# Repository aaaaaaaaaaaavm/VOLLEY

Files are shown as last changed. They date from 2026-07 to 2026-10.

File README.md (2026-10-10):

# VOLLEY

### A computational design study for sequential CubeSat deployment

VOLLEY studies a host-mounted electromagnetic machine that would feed ordinary 3U CubeSats through one reusable launch path and command an individual departure speed for each release. **Gen5 is the controlled academic evaluation snapshot, with a negative 3U selection finding.** Its final engineering release and academic freeze are open. Gen6 is the proposed first instrumented prototype programme, with its speed and accuracy to be derived from a named mission and payload. A 1 km/s-class release is a separate long-range research objective; Gen6 has no selected mechanism or validated performance.

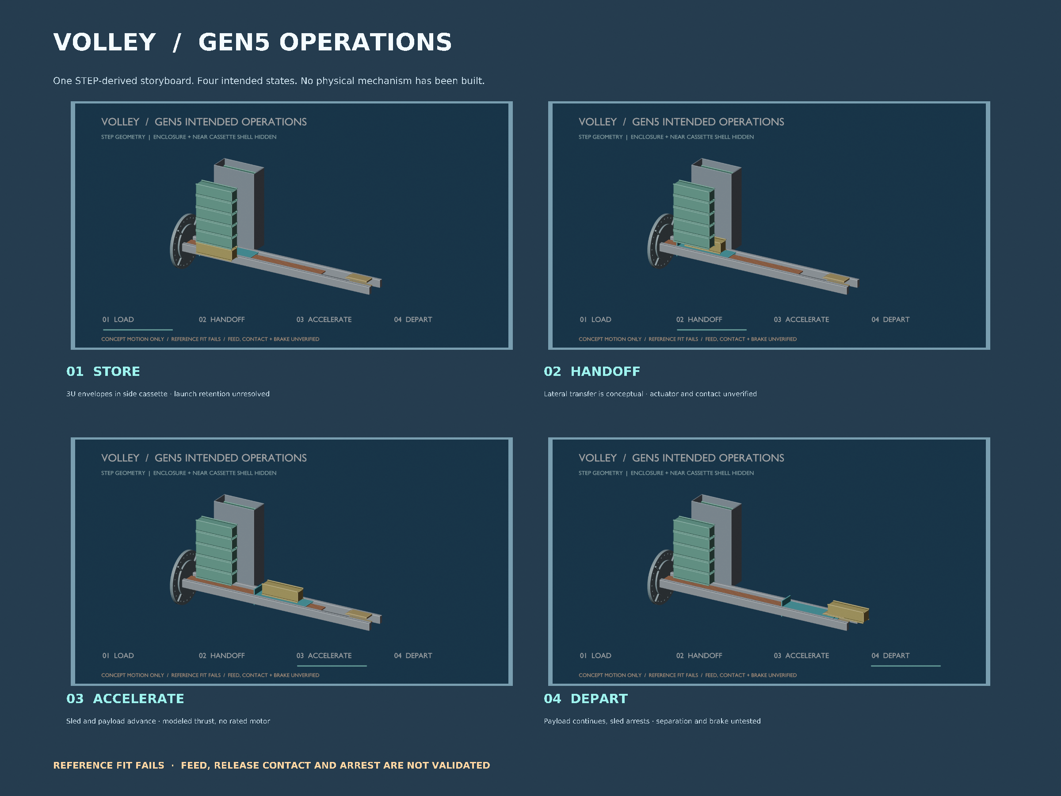
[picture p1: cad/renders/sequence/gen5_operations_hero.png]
Four-stage STEP-derived Blender storyboard of intended Gen5 storage, handoff, acceleration and departure


*Intended operations, not validated motion. The enclosure and near cassette shell are hidden for visibility. The evaluated side-fed assembly **fails** its static fit check; feed, contact and brake dynamics remain unverified. [Watch the eight-second conceptual animation](cad/renders/sequence/gen5_intended_sequence.mp4) · [inspect its STEP sources and provenance](cad/renders/sequence/README.md) · [open the interactive website](https://aaaaaaaaaaaavm.github.io/VOLLEY/).*

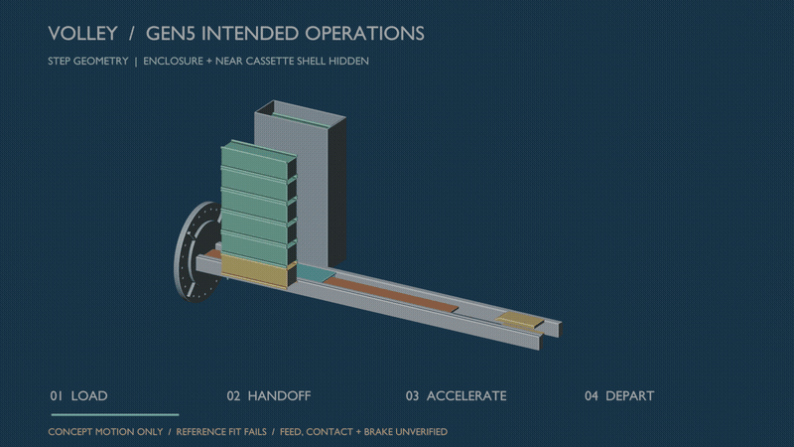
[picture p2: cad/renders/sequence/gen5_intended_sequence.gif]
Concept animation of intended Gen5 storage, lateral handoff, track motion and departure; motion is not validated


**Read first:** [Computational review report](reports/GEN5_COMPUTATIONAL_REVIEW.pdf) · [FreeCAD/CAD report](cad/GEN5_CAD_REVIEW.pdf) · [Gen5 freeze readiness](docs/GEN5_FREEZE_READINESS.md) · [Remaining CAD and IEEE work](IEEE_AND_CAD_REMAINING_WORK.md) · [IEEE prior-art update](docs/IEEE_PRIOR_ART_UPDATE_2026-10-09.md) · [Market and spacecraft fit](MARKET_AND_CUSTOMER_FIT.md) · [Gen5 technical closure](docs/GEN5_CLOSURE.md) · [Full baseline](docs/BASELINE.md) · [Evidence provenance](docs/PROVENANCE.md) · [Open problems](OPEN_PROBLEMS.md) · [CAD](cad/README.md) · [Validation](validation/README.md)

> **Evidence status, October 2026.** Gen5 is the selected computational design for academic review. Its configuration, model results and failed criteria are documented; [decisive verification items remain open](docs/GEN5_FREEZE_READINESS.md), so the final academic freeze has not been declared. No VOLLEY article has been built, fired, measured, qualified or flown; no complete installed-system or provider-specific interface has been validated. Published work on related systems is prior art and a source of assumptions, not a physical test of Gen5.

> **Decisive new finding:** the CAD finite-array/stator force screen gives **12.448 m/s only under ideal phase and omitted circuit losses**, versus **16.029 m/s** in the historical periodic-force shot model. The historical value below is retained for traceability, not an established Gen5 performance claim. [Force map and numerical limits](validation/P118_gen5_finite_force_map.md) · [Affected claims and rerun decisions](docs/GEN5_2026_10_09_FINDING_DISPOSITION.md).

An [independent 2-D finite-element screen](validation/P119_gen5_finite_force_fem2d.md) now checks the finite-array force decline using a magnetostatic PDE instead of the cuboid field law. It gives **1,081.6 J ideal in-plane work** on a 1 mm mesh, compared with **1,041.7 J** in the 3-D analytic screen. Depth effects and coupled electrical behavior remain open, so neither result is a motor rating.

A [depth-resolved 3-D surface-charge cross-check](validation/P121_gen5_finite_force_surface3d.md) independently evaluates the finite cuboids and all 162 stator belts. It recovers **1,041.7 J** ideal work, with 16-to-24 point face quadrature changing work by **0.00002%** and 25-to-12.5 mm station spacing changing it by **0.096%**. The separate [gap and depth scenarios](validation/P122_gen5_finite_force_sensitivity.md) show **906.7 J at a 14 mm gap** versus 1,041.7 J at 12 mm. These are ideal-phase model checks with shared magnetic material assumptions, not motor ratings or hardware tolerances.

> **Installed-system decision, 10 October 2026:** the [P123 one-event mass screen](validation/P123_gen5_one_event_mass_screen.md) finds **1.866 kg** less host fuel used by ideal finite-force Gen5 than a spring class when both carry 10 kg, against **54.562 kg** greater modeled device dry mass. With fuel re-solved for that one event plus equal reserve, Gen5 remains **52.717 kg heavier** on device plus fuel. Ideal-speed parity would require about **52.630 kg** less Gen5 device mass; that is a quantified redesign screen, not a full mission or motor rating. [Recompute from source](analysis/gen5_one_event_mass_screen.py) · [captured result](analysis/results/gen5_one_event_mass_screen.json) · [six-gate evidence programme](docs/GEN5_EVIDENCE_BUILD_PROGRAMME.md).

> **Necessary bound for the next design:** even a perfect release needing no host preburn would require Gen5 device mass **≤74.659 kg** to tie this one-event spring reference; today's model is 126.562 kg. The [reproducible bound](analysis/gen5_architecture_bounds.py) shows that motor speed alone cannot close this specific gap. A [captive passive-armature and integrated-structure hypothesis](docs/GEN5_H1_INTEGRATED_DEPLOYER_HYPOTHESIS.md) is an unselected research direction, not a revised Gen5 result or a verified invention.

> **Precision delivery must be specified by the orbit, not by speed alone.** The [P124 design-space screen](validation/P124_precision_delivery_design_space.md) converts declared 450 km orbit targets into ideal tangential increments and velocity-error budgets. It also shows that 1 km/s over the Gen5 1.3 m stroke implies about **39,220 g** for an ordinary 4 kg 3U payload. The first Gen6 prototype needs a payload and mission-derived speed/load specification; the 1 km/s goal remains separate long-range research.

The [P127 release/arrest bounds](validation/P127_gen5_release_arrest_bounds.md) find 731.8 J of sled kinetic energy at the **ideal** finite-force speed. Over the provisional 210 mm brake corridor, stopping it needs at least 37.6 g mean sled deceleration; the first-order host reaction and net recoil are also bounded. Eddy-current peak force, payload contact, host attitude and repeated-shot thermal behavior remain unsolved.

The [P126 R1 tolerance screen](cad/FEEDER_R1_TOLERANCE_SCREEN.md) uses the R1 CAD-derived 5 mm lateral gap and declared alignment bands. A 0.2° band retains 1.31 mm; a 0.5° band overlaps by 0.47 mm. These are assumed tolerances, not measured fit or accepted mechanism clearances.

> **P125 drive feasibility screen:** A quasi-steady, three-phase voltage/current model uses the finite Gen5 force map and the historical **unselected** winding and 96 V source. The reference surrogate reaches 12.448 m/s; halving the current limit gives 8.802 m/s and halving the initial source voltage gives 10.794 m/s. A single string at the older 116–185 mΩ commercial ESR bound **fails the source-power equation before release**; ideal parallel-string branches complete while multiplying source cells and mass. These are conditional model outputs, **not a rated release speed or selected drive**. [Method and limits](validation/P125_gen5_voltage_limited_screen.md) · [source](analysis/gen5_voltage_limited_screen.py) · [result](analysis/results/gen5_voltage_limited_screen.json).

The [Gen6 prototype-to-flight roadmap](docs/GEN6_PROTOTYPE_TO_FLIGHT_ROADMAP.md) sets explicit mission, architecture, predictive-model, measured-prototype, engineering-model, qualification and flight decision gates. These are proposed development stages, not achieved milestones.

Ideal speed, stroke and payload-load screen

One-event installed device plus resized-fuel comparison

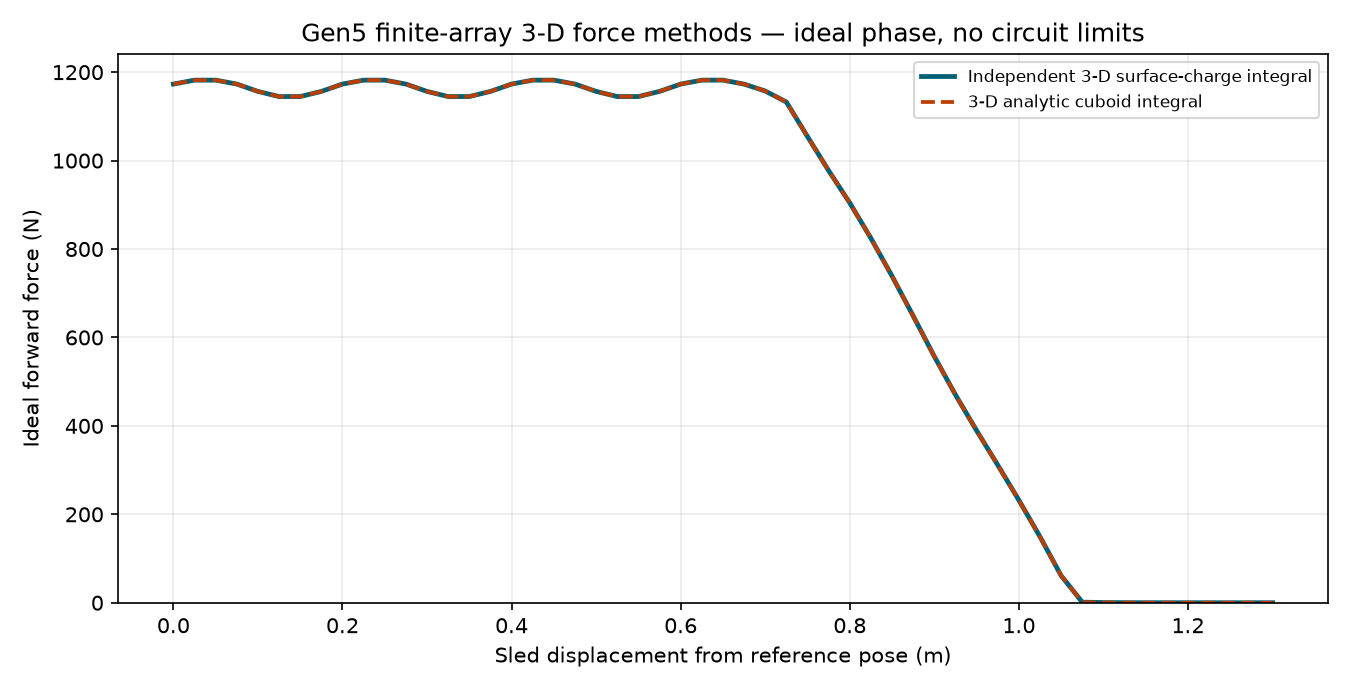
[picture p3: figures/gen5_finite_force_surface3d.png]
Independent numerical three-dimensional surface-charge force integration
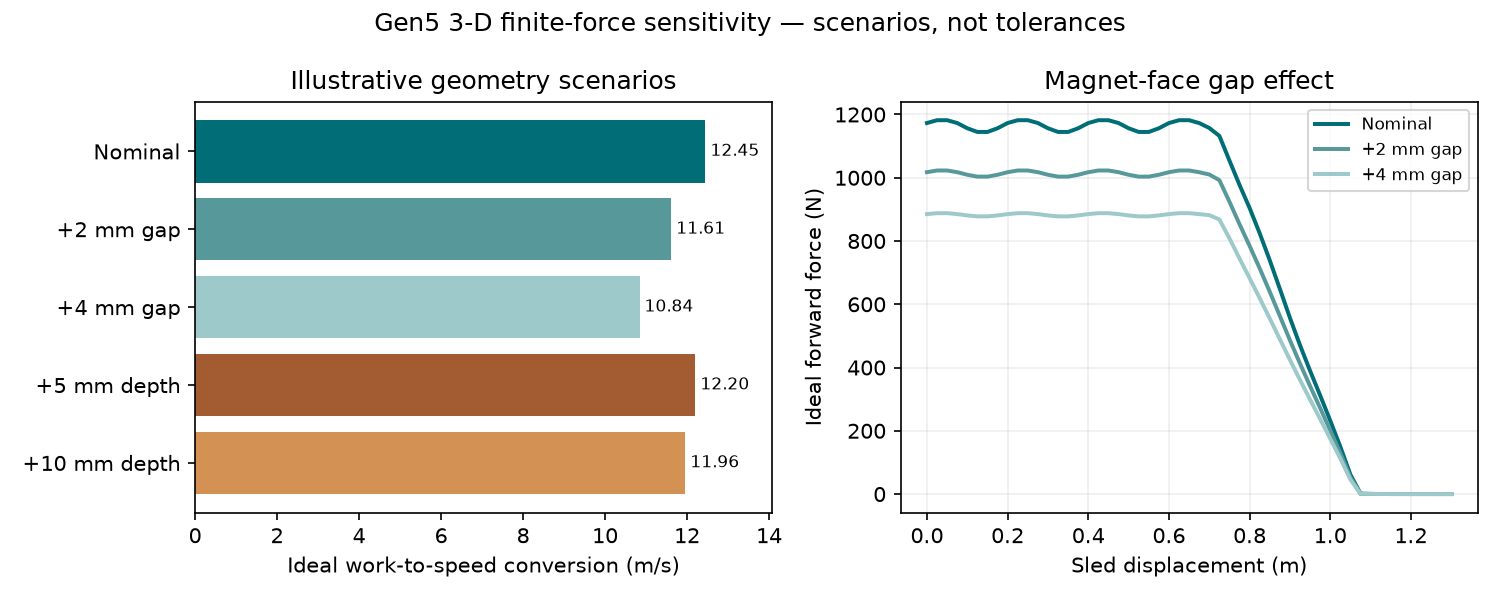
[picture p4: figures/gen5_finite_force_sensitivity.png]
Illustrative magnet gap and depth sensitivity scenarios


*Reproducible [P121 3-D numerical check](validation/P121_gen5_finite_force_surface3d.md) and [P122 deterministic scenarios](validation/P122_gen5_finite_force_sensitivity.md). The agreement checks the ideal finite-geometry integral; it does not select a winding, switching law or physical release speed.*

A [finite-force shot rerun](validation/P120_gen5_finite_coupled_shot.md) carries the P118 force profile through the historical capacitor/ESR model. With the old full-winding assumption it gives **12.448 m/s and 2.099 kJ gross draw**; a hypothetical segmented-copper branch gives the same ideal speed and **1.394 kJ**. These are conditional calculations using unselected power hardware and ideal phase at every position. The old energy, brake and precision figures cannot be transferred to them.

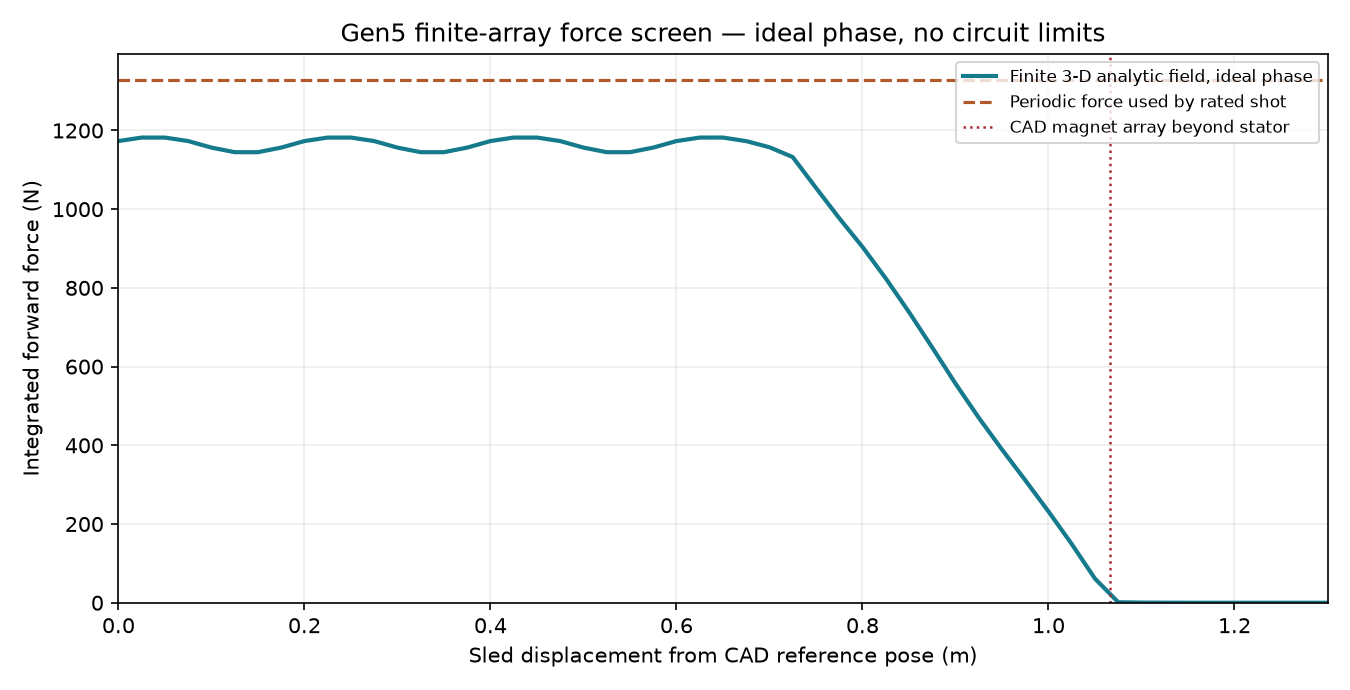
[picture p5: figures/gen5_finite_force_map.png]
Finite-stator force map and historical periodic assumption
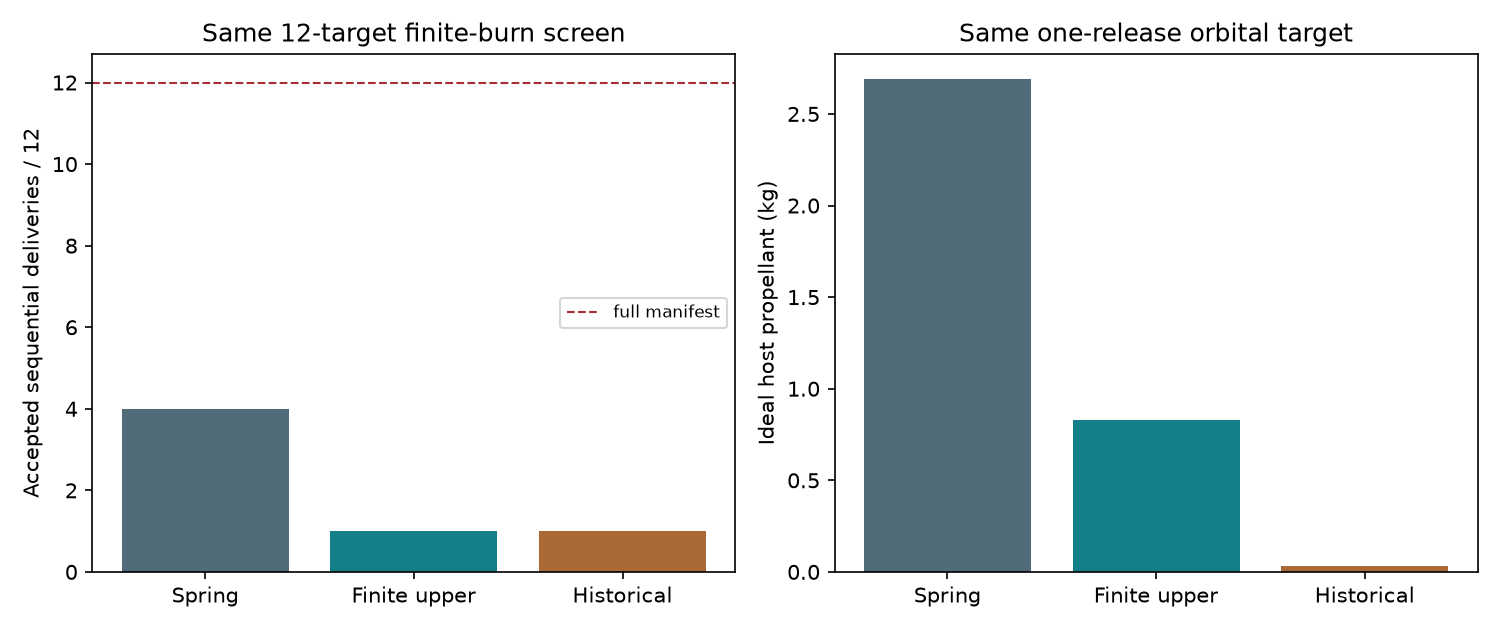
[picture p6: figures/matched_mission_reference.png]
Matched single-event and twelve-shot reference comparison


*New model screens: the finite-force result is analytic and shares the original magnetic field law; the matched mission uses assumed host and dispenser data. Neither is a physical result. [Mission assumptions and results](docs/MATCHED_MISSION_REFERENCE.md).*

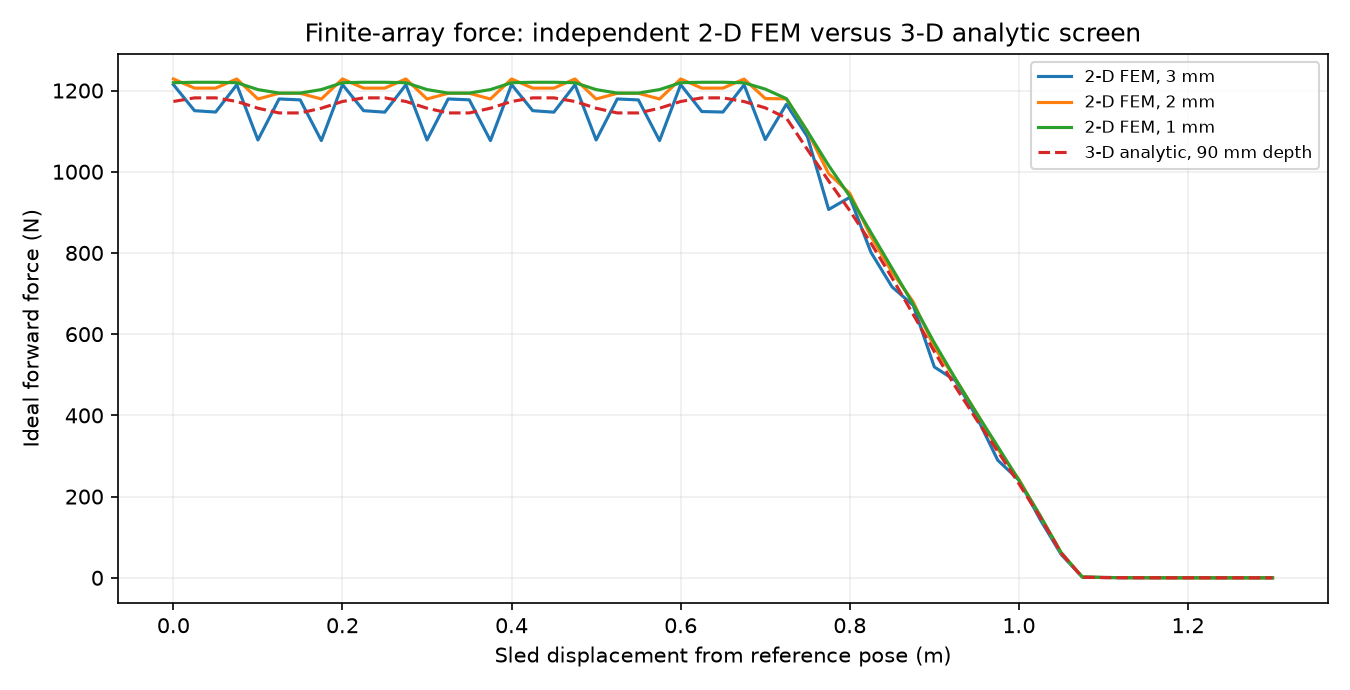
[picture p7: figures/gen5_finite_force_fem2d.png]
Independent two-dimensional finite-element force map compared with the three-dimensional analytic screen
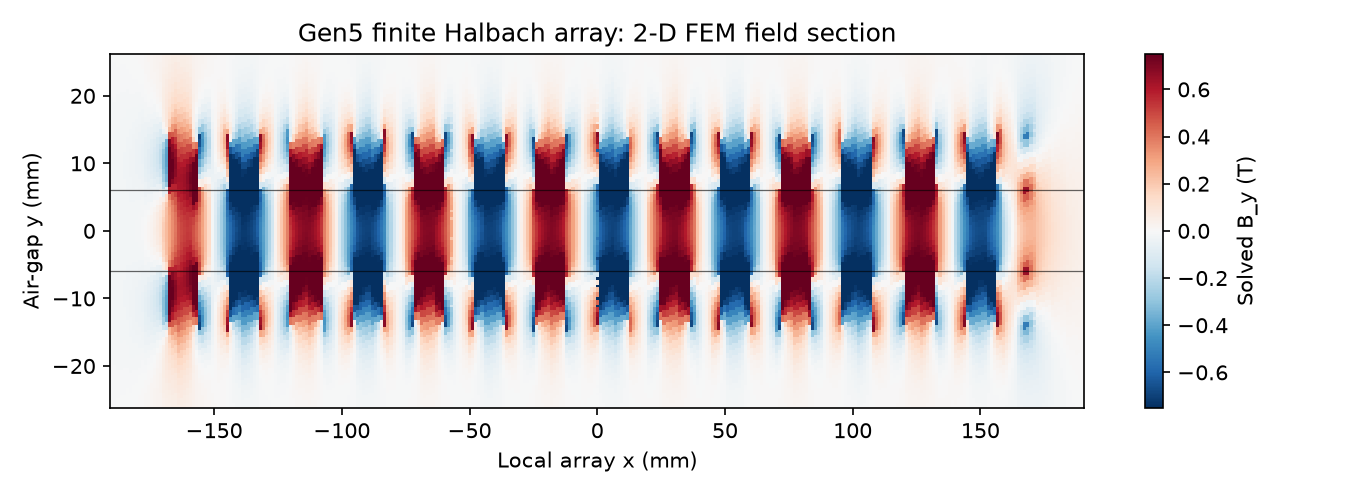
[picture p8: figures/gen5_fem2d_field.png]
Solved two-dimensional magnetic field around finite Halbach arrays


*Actual scikit-fem solver outputs, not CAD renders or physical measurements. The 2-D method omits finite magnet-depth effects; [P119](validation/P119_gen5_finite_force_fem2d.md) records mesh and boundary sensitivity.*

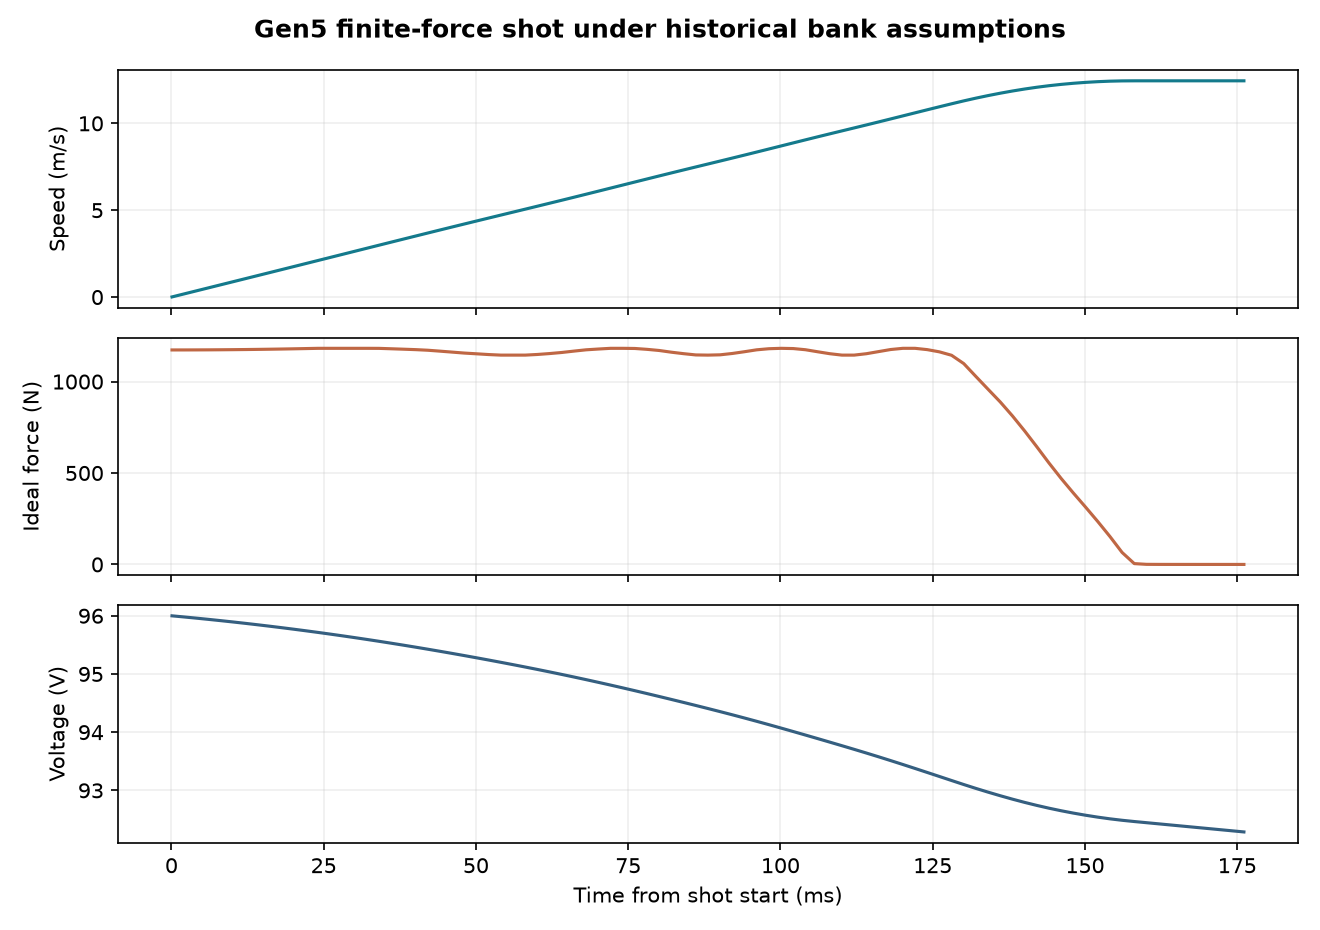
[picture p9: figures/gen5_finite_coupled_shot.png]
Finite-force shot under the historical bank assumptions


*Position-dependent model rerun, not a measured pulse or inverter validation. [P120 inputs, ledger and timestep check](validation/P120_gen5_finite_coupled_shot.md).*

## One machine, one evaluated configuration

Gen5 places the release station 1.5 m from the breech on 1.8 m structural longerons, with a 1.3 m powered stroke. It models a double-sided ironless Halbach linear synchronous drive, reusable permanent-magnet sled, eddy-current arrest, capacitor pulse store and conceptual twelve-payload magazine. The satellite is intended to remain mechanically and electrically unmodified. The modeled acceleration is **10.07 g**, but that value does not qualify any real payload.

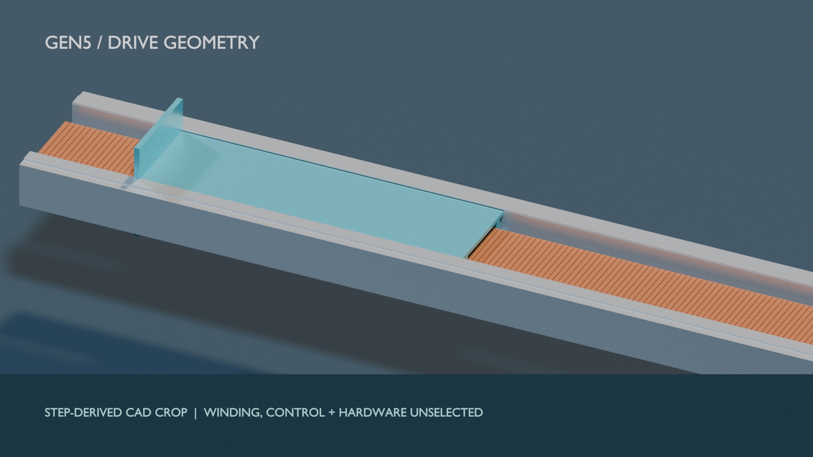
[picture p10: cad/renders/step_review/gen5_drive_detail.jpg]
STEP-derived Gen5 track, stator and sled geometry
<p align="center"><br><sub>Cropped reference CAD view. Switching, release contact and fabrication details are not defined by these solids.</sub></p>

| Gen5 model output | Result | Evidence boundary |
|:--|--:|:--|
| 3U exit speed | **16.029 m/s, historical periodic model** | Challenged by the finite-geometry force screen; not a demonstrated command range |
| Peak modeled acceleration | **10.07 g** | Payload-specific qualification remains open |
| Dry / loaded mass | **126.6 / 174.6 kg** | Modeled rollup using historical Gen3 sled volumes and assumed component masses; not complete installed-system mass |
| Electrical-to-payload efficiency | **18.8%** | Circuit and mechanics model, net of modeled recovery |
| Closed-loop exit-speed dispersion | **0.0274 m/s, 3σ** | Simulation with assumed sensor noise; not measured repeatability |
| Mass per carried 3U | **10.547 kg** | **Fails** the study's 2 kg/satellite economic screen by about 5.3× |

Values and definitions are in [the baseline](docs/BASELINE.md); scripts and machine-readable outputs are in [analysis](analysis/) and [validation](validation/). The [Gen5 closure](docs/GEN5_CLOSURE.md) records corrections and failed bands as part of the result.

<p align="center">Gen5 mass per 3U versus canister and economic screens Historical shot gross energy and modeled components</p>

*These charts are generated from the checked-in [mass](analysis/results/mass_properties.json), [shot](analysis/results/motor_results.json) and [energy audit](analysis/results/rated_energy_mass_audit.json) JSON. The 6 kg canister is an approximate comparator. [P117](validation/P117_rated_energy_mass_audit.md) now accounts for the old 124.488 J compact-output remainder as modeled converter loss, auxiliary draw and an integration step. The electrical hardware and revised finite-force shot remain unverified. [Rebuild charts](tools/plot_gen5_decision.py).*

## See the evidence, including what failed

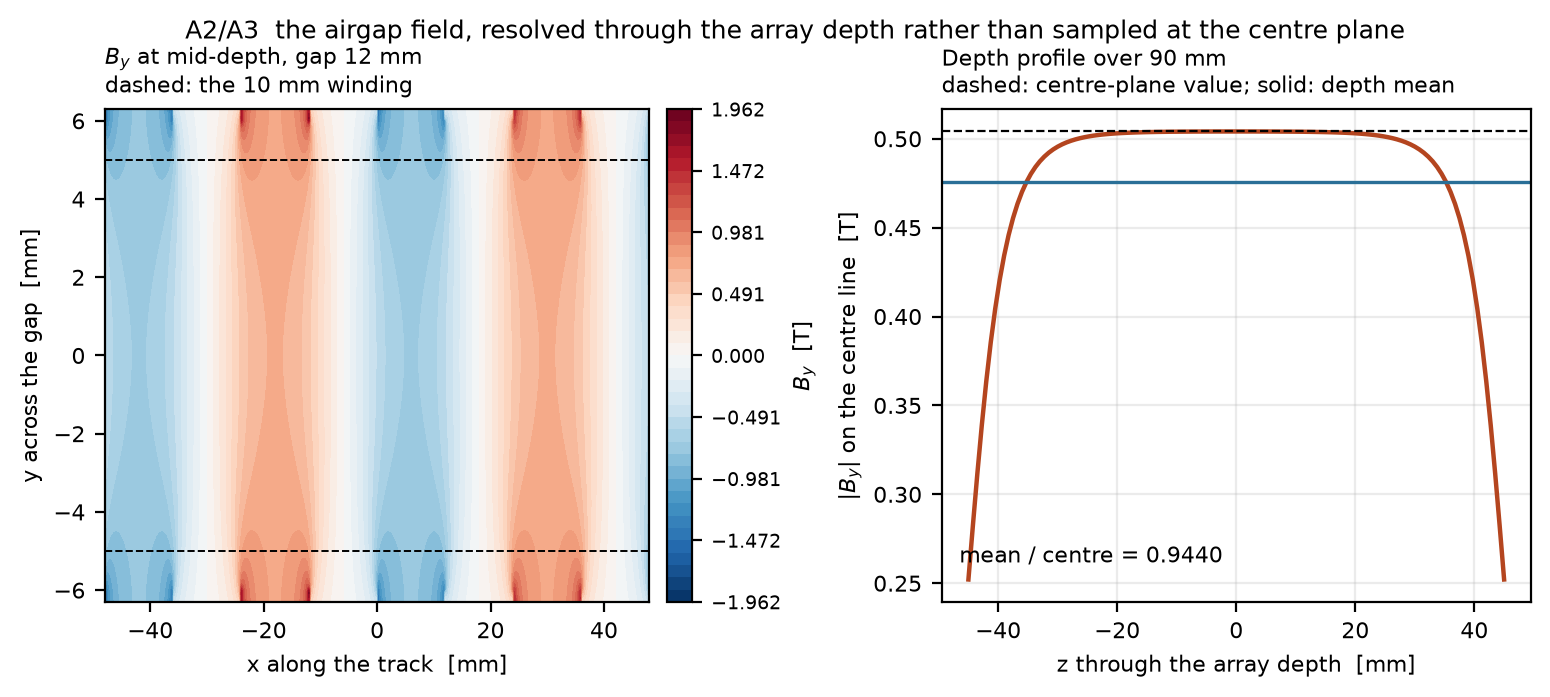
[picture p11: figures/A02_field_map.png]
Calculated magnetic airgap field
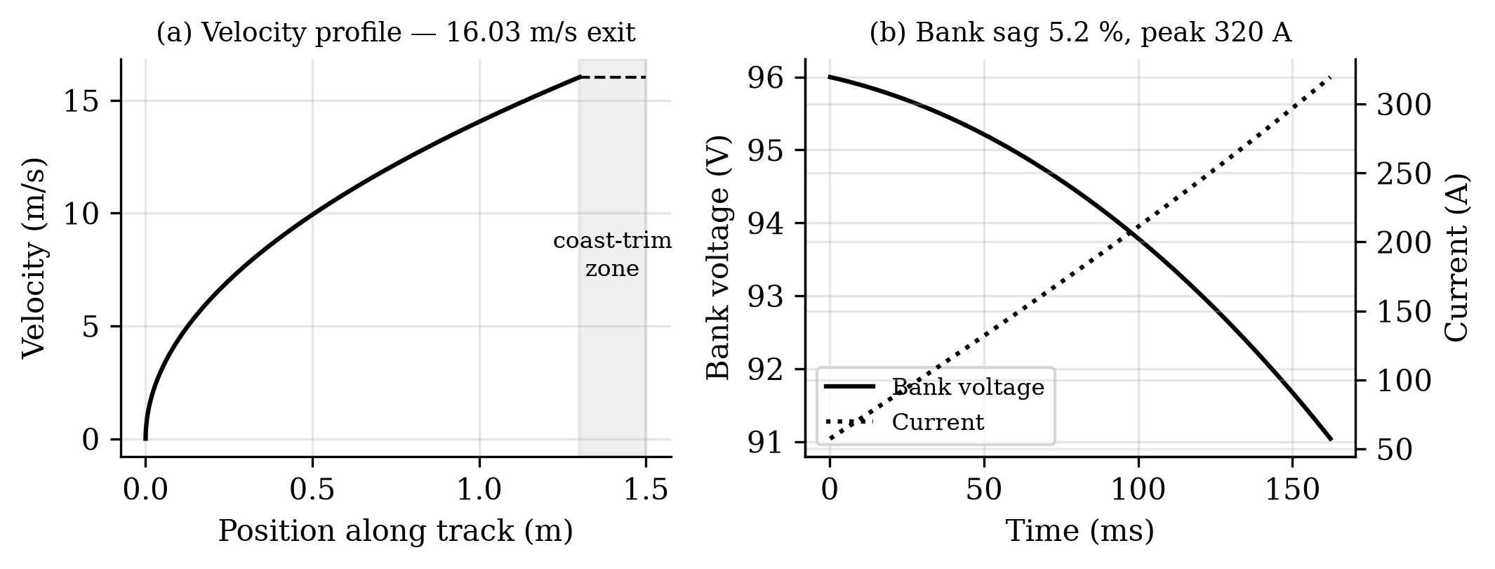
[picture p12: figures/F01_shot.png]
Calculated Gen5 shot history
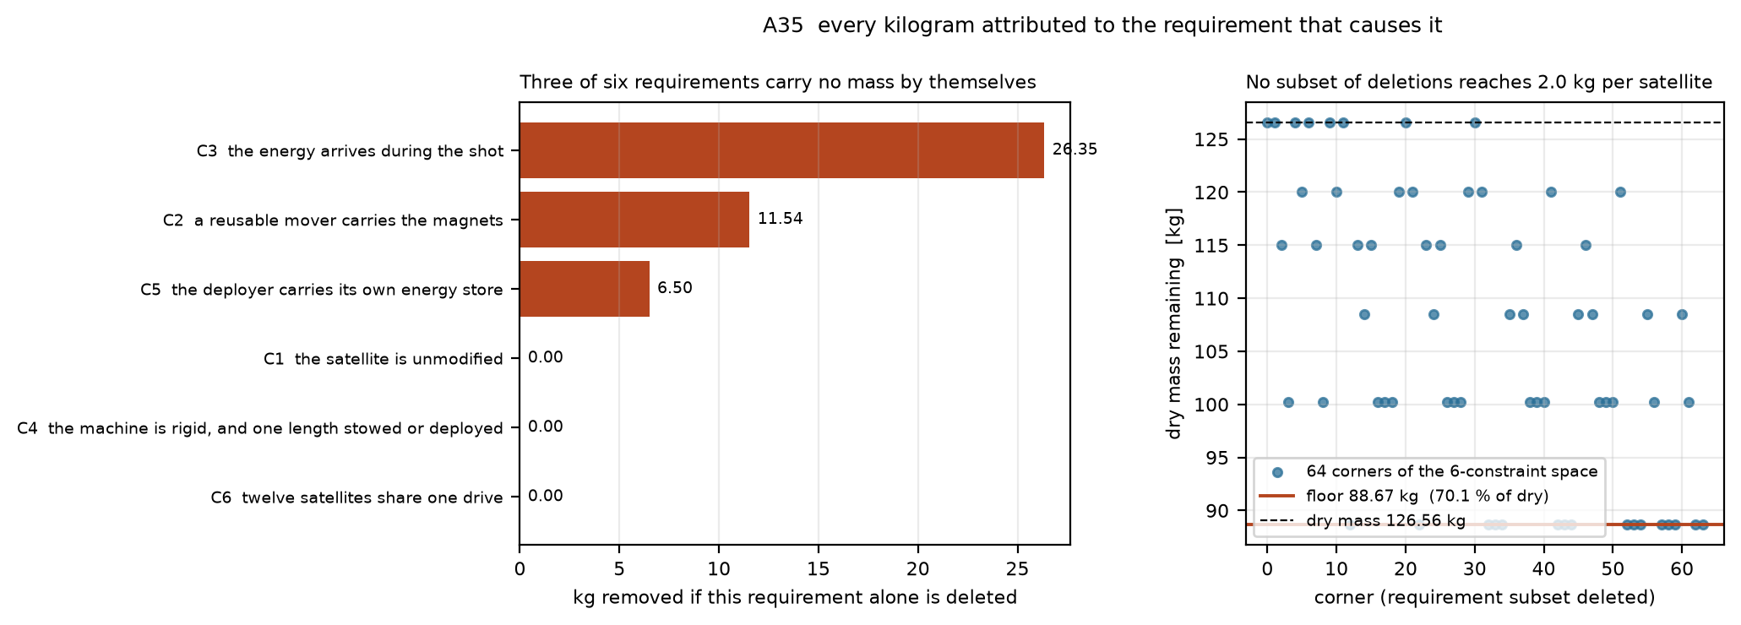
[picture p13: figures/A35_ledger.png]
Requirement-attributed mass floor


*Field model → modeled shot → mass verdict. P121 independently checks the ideal full-depth force integral under shared linear magnetic assumptions; neither that check nor the 2-D FEM validates hardware performance. The mass ledger leaves **88.67 kg (70.06%)** in its most favorable evaluated requirement-deletion corner, so the evaluated corners cannot meet the mass screen. [Methods and limits](docs/GEN5_CLOSURE.md).*

| Question | Best available answer | Where to inspect it |
|:--|:--|:--|
| Does the field model agree with other methods? | Analytic field compared with magpylib and meshed 2-D/3-D field solves; checks apply to stated field quantities. | [A1](validation/A1_field_femm.md), [validation register](validation/README.md) |
| Does the electrical shot model agree with circuit simulation? | ngspice cross-check also exposed an omitted bank resistance loss. | [Gen5 closure](docs/GEN5_CLOSURE.md), [validation register](validation/README.md) |
| Does the CAD survive all criteria? | No. The revised enclosure is **50.04 kg**, and the new reference assembly exposes an **11 mm side-fed width shortfall** plus exact track/cassette interference. | [CAD record](cad/README.md), [assembly screen](validation/P116_gen5_assembly_packaging.md), [mass ledger](validation/A35_constraint_ledger.md) |
| Does a complete twelve-payload mission close? | No complete delivery in the six sampled finite-burn cases; best case delivered **5/12**. This is a bounded screen, not an impossibility proof. | [Finite-burn study](docs/MANIFEST_FINITE_BURN.md) |
| Has the concept been independently tested? | Selected numerical cross-checks exist. Hardware, host integration, release reliability and payload compatibility remain untested. | [Provenance](docs/PROVENANCE.md), [open problems](OPEN_PROBLEMS.md) |

<p align="center">Bounded two-payload mission timing screen Operational uncertainty study</p>

*These are model studies with stated assumptions. The sampled 4.57 m/s two-payload point is a mission-screen result, not a launcher maximum or a validated setting. [Timing assumptions](docs/MANIFEST_TIMING.md) · [Uncertainty study](docs/OPERATIONAL_UNCERTAINTY.md).*

Corrected same-epoch phase comparison

*A 468 s wait alone produces no persistent relative phase in the zero-impulse case. The nonzero curves require a differential release impulse; host maneuver and drag cases remain to be compared on matched missions. [Correction and method](docs/PHASING_CORRECTION_2026-10-09.md).*

Independent two-body check of the rated 450 km orbit case

*A separate Cartesian integrator recovers **28.800775 km** of immediate semi-major-axis rise for the modeled 16.029 m/s prograde shot. This checks two-body orbit geometry only; the 1.60 lifetime estimate, host campaign and flight performance remain unverified. [Method and numerical band](validation/P115_rated_orbit_cartesian.md).*

Accepted delivery prefixes in the six sampled finite-burn campaigns

*The finite-burn campaign has been rerun from the restored source and again stops at 0/3/4/0/4/5 accepted deliveries. No case delivers all twelve. This is a surrogate calculation with assumed host thrust and release speeds; it does not establish mission infeasibility or hardware performance. [Run record and limitation](docs/MANIFEST_FINITE_BURN.md).*

## Inspect the hardware definition

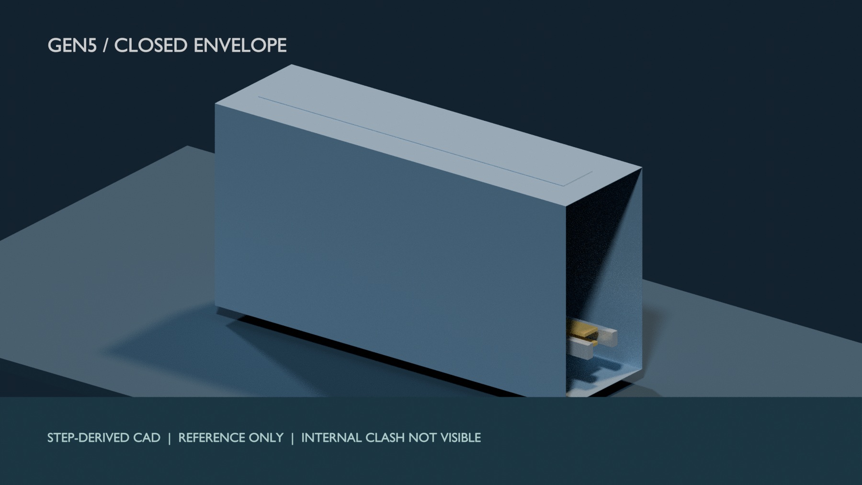
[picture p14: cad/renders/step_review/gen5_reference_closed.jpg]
STEP-derived outer Gen5 reference envelope, which conceals an unresolved internal clash
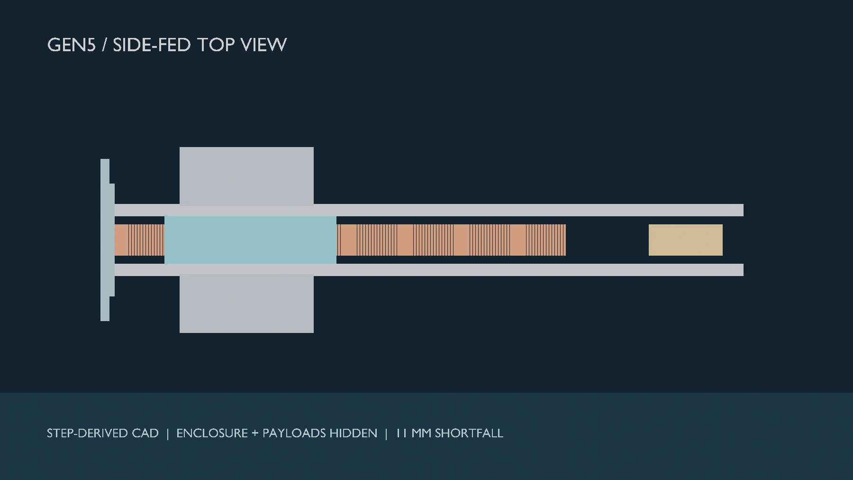
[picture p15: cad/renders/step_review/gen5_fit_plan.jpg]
STEP-derived top view of the Gen5 side-fed reference arrangement


*Left: closed external envelope; the internal clash cannot be seen from outside. Right: enclosure and payloads hidden to inspect the side-fed track/cassette placement. The [exact-solid packaging result](validation/P116_gen5_assembly_packaging.md), rather than pixel measurements, establishes the 11 mm shortfall.*

The [Gen5 STEP parts](cad/step/gen5/), [native FreeCAD document](cad/native/Gen5_Review.FCStd), [FreeCAD assembly STEP](cad/step/gen5/VOLLEY_Review_Assembly_FreeCAD_Gen5.step), [renders](cad/renders/gen5/), [layout](figures/D02_layout.png) and [CAD audit](cad/GEN5_CAD_REVIEW.pdf) are reviewable design artifacts. The reference assembly **fails** the stated side-fed placement screen:

Gen5 reference assembly transverse packaging conflict

*The two 166 mm cassettes and 205 mm track require 537 mm across an internal 526 mm width before clearance. Exact STEP-solid intersection finds 32,915 mm³ overlap per cassette in the reference placement. [Rebuild and inspect](validation/P116_gen5_assembly_packaging.md).*

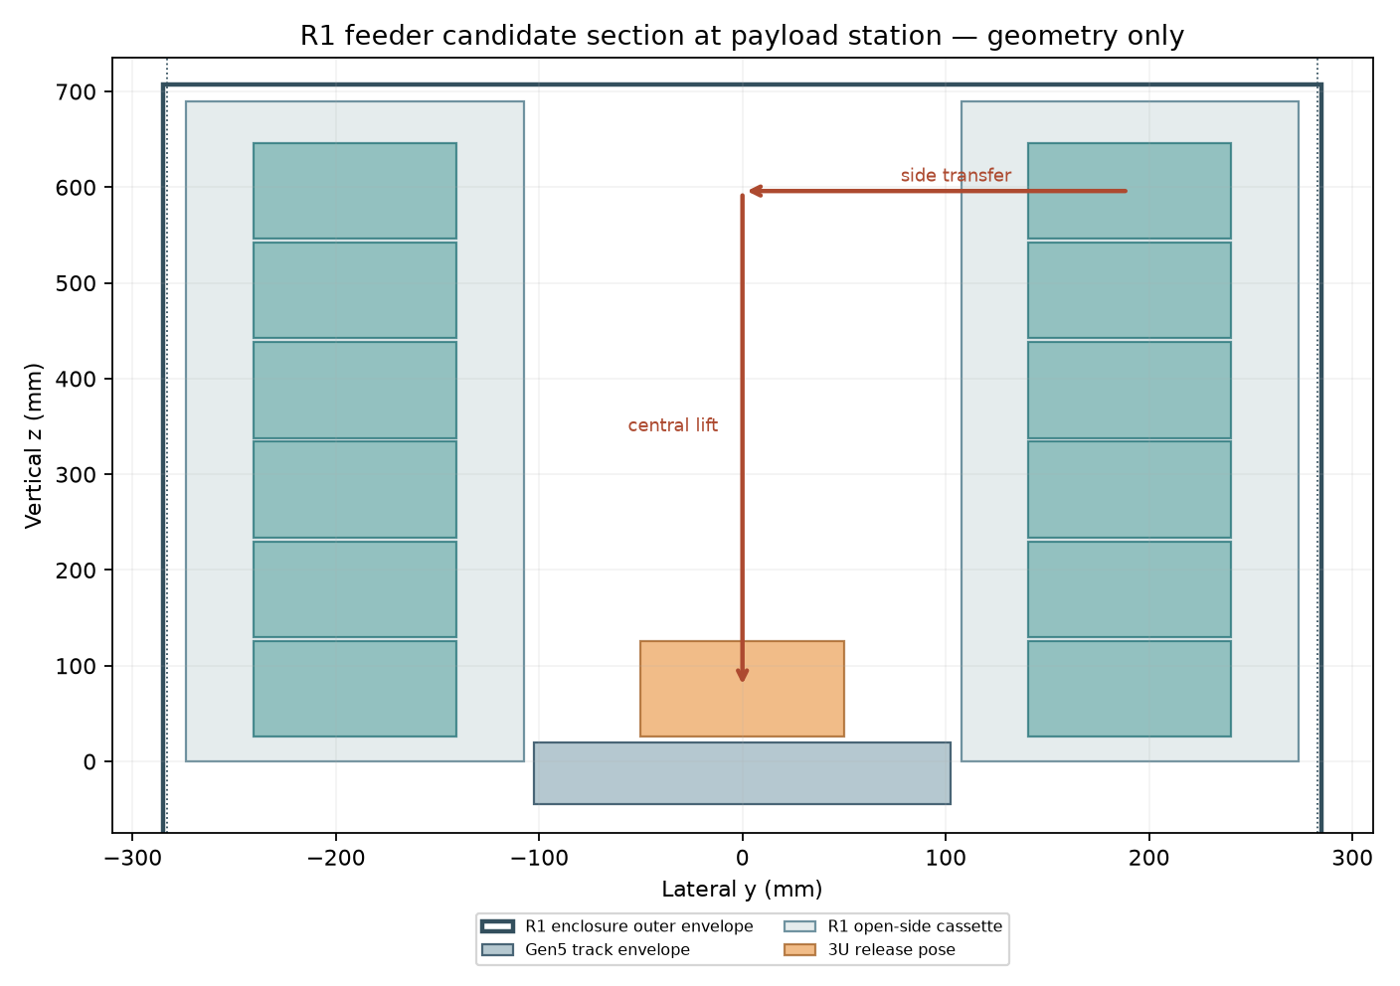
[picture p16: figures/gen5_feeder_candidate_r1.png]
Unselected R1 feeder geometry section


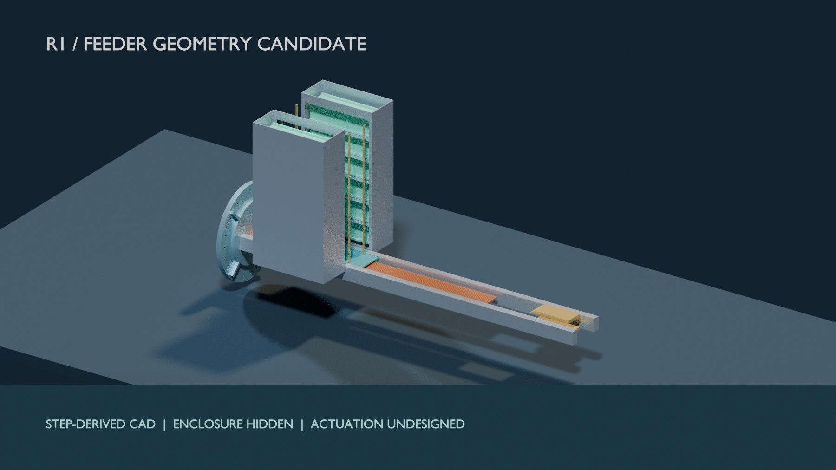
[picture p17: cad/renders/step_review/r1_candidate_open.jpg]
STEP-derived unselected R1 widened feeder candidate
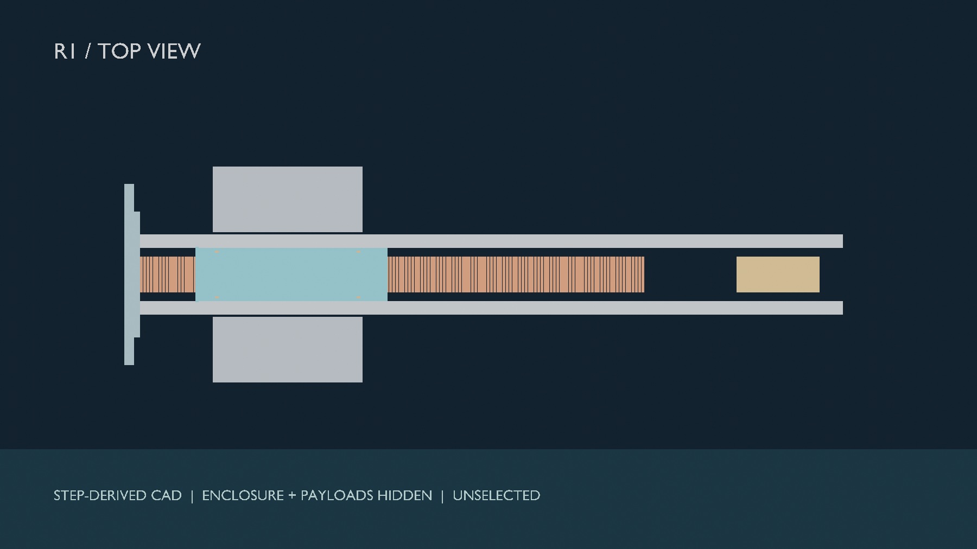
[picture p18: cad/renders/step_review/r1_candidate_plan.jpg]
STEP-derived top view of the R1 feeder candidate


*An [unselected R1 feeder geometry](cad/FEEDER_CANDIDATE_R1.md) widens the enclosure to 570 mm and clears twelve scripted envelope routes and fixed-part swept-box checks. The [native FreeCAD document](cad/native/Feeder_Candidate_R1.FCStd) and [STEP files](cad/step/feeder_candidate_r1/) are review artifacts. No lift mechanism, retention, tolerances, supplier mass or approved host interface is defined; R1 does not change the evaluated Gen5 results.*

The CAD does not provide manufacturing drawings, tolerance stacks, an approved ICD or proof of buildability.

## From study to product

Sequence from host preparation to repeated release

The sequence above is the product intent. The decisive next gates are a named host and deployment ICD; complete installed mass and thermal, power and structural budgets; feeder, retention, recoil and jam-recovery design; payload-specific loads; uncertainty and full-manifest mission closure; then representative calibrated multi-shot hardware testing. The [gap register](OPEN_PROBLEMS.md) keeps failed and unrun items visible.

For the **first Gen6 prototype**, choose a test speed and tolerance from a named mission and payload load limit; do not inherit the 1 km/s target. For the separate high-speed research stream, ideal constant-acceleration scaling gives about **5.1 km of stroke at 10 g** or **204 m at 250 g** for 1 km/s, before losses, arrest, thermal design or payload qualification. A radically different payload class, host or architecture may be required. [Scaling illustration](docs/assets/scaling.svg) · [programme decisions](docs/PROGRAMME_EXECUTION.md).

## Explore the programme

| Repository | What a reader gets |
|:--|:--|
| **This repository** | Full engineering record, code, results, CAD, validation and unresolved defects |
| [VOLLEY-thesis](https://github.com/aaaaaaaaaaaavm/VOLLEY-thesis) | Self-contained final-year manuscript, college review material and local evidence package |
| [VOLLEY-paper](https://github.com/aaaaaaaaaaaavm/VOLLEY-paper) | Self-contained IEEE-formatted manuscript and reproducibility package; venue not yet selected |
| [VOLLEY-lab](https://github.com/aaaaaaaaaaaavm/VOLLEY-lab) | Explored, rejected or gated alternative architectures and the reasons they stopped |

**Reproduce and audit:** [verification entry point](tools/verify_all.sh) · [four-repository adversarial review](docs/FOUR_REPO_AUDIT_2026-10-09.md) · [figure index](docs/FIGURE_INDEX.md) · [literature](docs/LITERATURE.md) · [prior art](docs/PRIOR_ART.md) · [change history](CHANGELOG.md). Review acceptance bands and failures before citing any headline number.

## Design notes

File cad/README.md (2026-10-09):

# CAD

> **Current academic configuration: Gen5.** Start with the [eight generated Gen5 STEP
> parts](step/gen5/), [20-instance reference assembly](step/gen5/VOLLEY_Review_Assembly_Gen5.step), [Gen5 renders](renders/gen5/), [dimension sheet](DIMENSIONS.md),
> [configuration hashes](../docs/GEN5_CONFIGURATION_INDEX.json) and
> [freeze-readiness matrix](../docs/GEN5_FREEZE_READINESS.md). The Gen3 Fusion files below
> are historical source geometry used in some mass/FEA records; their age and role must
> accompany any citation. The reference assembly has a [measured side-fed clash](../validation/P116_gen5_assembly_packaging.md): 11 mm width shortfall and track/cassette intersection. It is a controlled review artifact, not an approved integrated design, manufacturing drawing or physical fit test.
>
> The 9.445 kg modeled sled value was adopted from Gen3 solid volumes and tested with
> the A4 CalculiX chassis idealization. It is carried into Gen5; the Gen5 STEP build
> checks dimensions but does not independently recompute an installed mass for all
> hardware. The 126.6 kg dry rollup includes modeled and assumed components, so it
> must not be described as the weight of a complete verified Gen5 CAD assembly.

**Professional CAD handover:** [native FreeCAD 1.0 review document](native/Gen5_Review.FCStd), [eight FreeCAD-exported STEP parts](step/freecad_gen5/), [FreeCAD assembly STEP](step/gen5/VOLLEY_Review_Assembly_FreeCAD_Gen5.step), [read-back and interference report](FREECAD_EXPORT.json), and [three-page CAD review PDF](GEN5_CAD_REVIEW.pdf). The source B-reps were created parametrically in CadQuery and imported into FreeCAD; the imported parts do not contain native FreeCAD feature histories. Both FreeCAD and CadQuery report the same stated side-fed track/cassette clash. The PDF includes a model render and measured section, each labeled by evidence type.

**New visual review set:** [six labeled STEP-derived Blender JPEGs and source hashes](renders/step_review/README.md) show the reference assembly open, closed and from above, a cropped drive detail, and the separate R1 candidate. The image pipeline reopens each source STEP in FreeCAD and checks its placed bounds and volume against the native review document before rendering. The views describe geometry only; a rendered surface is not a physical or manufacturing validation.

**Unselected R1 feeder geometry:** [review report](FEEDER_CANDIDATE_R1.pdf), [native FreeCAD document](native/Feeder_Candidate_R1.FCStd), [part and assembly STEP](step/feeder_candidate_r1/) and [exact-solid collision ledger](FEEDER_CANDIDATE_R1.json). A 570 mm enclosure clears the scripted 3U envelope routes, but the actual lift, restraint, fault recovery and changed installed mass are not designed. R1 is a separate candidate, not a revision of the evaluated Gen5 configuration.

> ## historical study is here too, and it is a different machine
>
> [ADR-032](../docs/adr/032-legacy_study-stage-integrated-gas-store.md). The payload is accelerated
> directly by cold gas along a rail the host stage provides, no mover, no stator, no brake, no
> return stroke. `cad/build_legacy_study.py` generates it from the same `parameters.json`, and it is
> byte-stable across rebuilds like Gen5.
>
> Seven exported parts, and only one of them is inherited: the magazine cassette. A36 and A37 agree from
> opposite directions that the containment is the only subsystem surviving every architecture
> deletion.
>
> | | |
> |---|---|
> | Bore / stroke | 15.805 mm / 8000 mm, A49, the host stage's whole acceleration length |
> | Chamber | 2 L at 22.7258 bar, A41 sized it, ADR-034 set the charge |
> | Reservoir | 3.46 L at 200 bar, A56, sized rather than scaled |
> | Exit velocity | 29.01 m/s at the friction allowance, 11.36 g peak |
>
> Corrected 2026-08-22, [P107](../OPEN_PROBLEMS.md). These three rows read 50 bar, 11.25 L
> and 30.54 m/s at 25 g, the pre-ADR-034 design point. The geometry never moved with them:
> `build_legacy_study.py` reads every one of these from `parameters.json`.
>
> Three things it draws that are not settled, and they are in the script's own header rather
> than only here: the cradle is an envelope, not a design, because A34 says the mechanism
> does not exist and A38's preload is 201.7 N at the 25 g cap against 91.7 at the design point
> (P102); the reservoir is sized but the bottle itself is not designed; and the stage rail is
> a straight extrusion
> of unknown provenance, because no launch provider has agreed to anything.

Fusion 360 CAD for VOLLEY, across nine documents (Track, Stator, Sled, Payload_3U,
Magazine_Cassette, Brake, Interface_ESPA, Enclosure, Assembly), in three generations.

Full generation history, per-file body counts, and the defect list are in
[`CHANGELOG_CAD.md`](CHANGELOG_CAD.md).

## Two implementations of the same geometry

`build_gen5.py` (CadQuery, B-rep, STEP) and `scad/gen5.scad` (OpenSCAD, CSG, STL) build the same
eight documents from the same parameter file and read nothing of each other's.
`tools/compare_scad_cadquery.py` compares them part by part. It found a real defect on its first
run, the sled rollers were outside their channels in every Gen5 STEP ever built, P71,
which no guard here could have caught, because every guard compares a built artifact against
the script that built it. See [`scad/README.md`](scad/README.md).

## Generations

| Folder | What it is | Status |
|---|---|---|
| `step/gen5/` | Generated from `parameters.json`; eight STEP parts with 23 read-back dimension checks and one 20-instance reference assembly | **Current academic geometry**, documented interference and conceptual interfaces |
| `step/gen3/` | Parameter-reconciled Fusion revision, plus `EMOCD_Gen3.step`, a monolithic single-file model (395 solids) holding all nine sub-systems | **Historical mass and FEA source**; not the Gen5 release geometry |
| `step/gen2/` | First structured revision. Mechanism-level detail arrives: single-layer stator, sled Halbach arrays and rollers, magazine escapement and D6 pins, brake ring spring | SUPERSEDED, carries a 360 mm sled chassis where the spec says 488 mm |
| `step/gen1/` | The original CAD, 2021-2025. Structural envelope rather than mechanism model; the geometry `parameters.json` was reverse-engineered from. Includes the pre-split single-file `EMOCD_Deployer_Assembly_Gen1.step` and a second sled revision, `Sled_Gen1b` | SUPERSEDED, heritage only |

Use Gen5 for the current design. Use Gen3 only when tracing the earlier volume or A4 FEA evidence.

## What is authoritative here

- `parameters.json` is the geometry source of truth. Every dimension lives here, not
  in Fusion (Fusion user parameters are document-scoped and drift silently across the nine
  documents). Change a value here, then regenerate the affected document from script. If
  the CAD and `parameters.json` disagree, `parameters.json` wins and the CAD is wrong.
- CAD is authoritative for geometry, fit, and interference only.
- `analysis/*.py` remains authoritative for mass and performance. Fusion-computed
  masses are proxies (solid-copper stator, solid-aluminium CubeSats, steel standing in for
  NdFeB) and are deliberately excluded from `parameters.json`. Never quote a
  Fusion-computed mass.

## Historical status note (2026-07-28)

At that date this was first-pass CAD, with no structural or magnetic FEA behind it. Several values were
flagged `PROVISIONAL_PENDING_FEA` in `parameters.json`. Open: the sled chassis mass (P5),
the resulting exit velocity (P8), the ESPA envelope overrun (P9), the incomplete mass
rollup (P10), and the CAD-side geometry defects P14, see `../OPEN_PROBLEMS.md`.

What changed on 2026-07-28. The previously committed `step/*.step` set was a
mixed-generation snapshot matching no single generation, and two of its files were stubs:
the stator export contained one solid rather than 162 conductors, and the ESPA
interface contained one solid rather than a flange ring, hub plate, and four gussets.
It was replaced wholesale by the three audited generations. See `CHANGELOG.md` (CAD2 block)
and `OPEN_PROBLEMS.md` P13.

## Before using any file

1. Gen5 for current geometry; Gen3 for the cited historical mass and FEA input. Gen1 and Gen2 carry known dimensional and mechanism
   defects, listed per file in `CHANGELOG_CAD.md`.
2. Cross-check every dimension against `parameters.json` before quoting it.
3. No uncorrected Fusion masses. The modeled mass authority is `analysis/mass_properties.py`;
   its 126.6 kg rollup includes assumptions and is not a measured or complete installed mass.
4. The sled mass conflict was dispositioned on 2026-07-29. The scripts now carry 9.445 kg from Gen3 solid volumes. The historical periodic-force model predicted **16.029 m/s** after a depth correction; [P118](../validation/P118_gen5_finite_force_map.md) and the independent 2-D [P119](../validation/P119_gen5_finite_force_fem2d.md) finite-array checks challenge its force input, so no current speed rating is selected. Historical note follows: 20.37 m/s assumed a 4.86 kg sled; the Gen3
   geometry implies ~7.50 kg and a provisional 17.88 m/s. Quote neither without the
   conflict (P5, P8). `validation/A4_sled_structural.md` is the analysis that settles it.
5. The ESPA comparison fails: 1839 mm installed against a quoted ~1270 mm class
   envelope, about 44 % over (P9). No host provider has approved an interface; P12
   records the historical compatibility claim and its correction.
6. The stator layer count is an open design decision. Gen1 built two layers, Gen2 and
   Gen3 one, and `parameters.json` flags it open. The electromagnetic consequence, roughly
   x2 force for the same current against x2 copper mass and winding complexity, has never
   been computed (P14).

> Modelling from this repository? [`../CAD_BRIEF.md`](../CAD_BRIEF.md) is written to be read
> first: coordinate frame, part list and assembly order, critical versus soft dimensions, and a
> table resolving every conflict between files here with the side to build. `DIMENSIONS.md`
> and `BOM.md` below are built from `parameters.json` and `analysis/mass_properties.py`, so
> they cannot drift from their sources.

## Contents

- `parameters.json`, the 9-group geometry parameter set, source of truth
- `CHANGELOG_CAD.md`, generation history, per-file inventories, defect IDs (G1-D*, G2-D*,
  G3-D*), and the cross-generation comparison
- `step/gen1/`, `step/gen2/`, `step/gen3/`, STEP exports from Fusion (`.f3d` is not diffable,
  so STEP is what gets committed)
- `step/gen5/`, built by `build_gen5.py` from `parameters.json`, nothing is drawn, so
  it cannot drift from the parameters, it regenerates byte-identically from a clean clone, and
  `build_gen5.py --check` reads 23 dimensions back out of the built solids and compares them to
  the parameter file. See [ADR-026](../docs/adr/026-cad-built-from-parameters.md).
  It is a geometry and interface model, not a manufacturing model: no fillets, no chamfers,
  no fasteners, no harness routing, no tolerancing. Do not send it to a machine shop; do use it
 to check fit, envelope, clearance and station alignment
- `renders/gen5/` is the current Gen5 presentation set generated from the Gen5 geometry.
  `renders/` and `renders/source/` also retain older Gen4 frames prepared by
  `tools/prepare_renders.py`; those have no matching committed Gen4 STEP export and must
  be captioned as historical. `exploded_view.png` comes from the Gen3 monolithic model.
  No performance number is taken from a render.
- `tools/prepare_renders.py`, which crops the raw frames to content, fits them to a
  publishing box and draws the departure direction on each. The direction is per-render
  because the camera flips between views; P43 is what happens when it is wrong
- `DIMENSIONS.md` and `BOM.md`, built by `tools/make_cad_package.py` from
  `parameters.json` and `analysis/mass_properties.py`. Both are guarded by
  `tools/check_artifacts.py`, so a dimension changed without a regenerate is caught
- `tools/make_cad_package.py`, the generator. Edit the sources and re-run it; never edit
  `DIMENSIONS.md` or `BOM.md` directly

The 2-D magnetic cross-section and its FEMM run sheet live in `../analysis/femm/`.

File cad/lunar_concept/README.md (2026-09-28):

# Current mechanical and lunar concept CAD

> **Architecture disposition, 2026-09-28:** The separate motor-charged spring-cell bank is withdrawn as VOLLEY's next architecture. It is retained here only as a dated study. Any selection or current-reference wording below describes the former decision and is superseded. A reusable shared launch path with sequential loading is the open design objective; no speed envelope is validated. See [current status](../../docs/NEXT_GENERATION_STATUS.md).

Adityavardhan Mishra

All dimensions are in mm; +X is departure. These are named component envelopes,
not native Fusion timelines, selected parts or manufacturing-ready drawings.
MC-L2 uses an 80 mm working-stroke target. The carrier bus/tank intentionally
contain overlapping system envelopes. Do not infer installed mass or clearance
approval from these models.

| Assembly | STEP | STL |
|---|---|---|
| Mechanical cell | [Download](mechanical_cell.step) | [Download](mechanical_cell.stl) |
| Four-cell bank | [Download](four_cell_bank.step) | [Download](four_cell_bank.stl) |
| Lunar carrier | [Download](lunar_carrier.step) | [Download](lunar_carrier.stl) |
| Larger-payload pallet | [Download](large_payload_pallet.step) | [Download](large_payload_pallet.stl) |

[Interactive viewer](https://aaaaaaaaaaaavm.github.io/VOLLEY/lunar.html#architecture)
· [Engineering review](../../docs/LUNAR_VISUAL_REVIEW.md)
· [Fusion handoff](../../docs/CURRENT_CELL_FUSION_HANDOFF.md)
· [Generator](build_concepts.py)

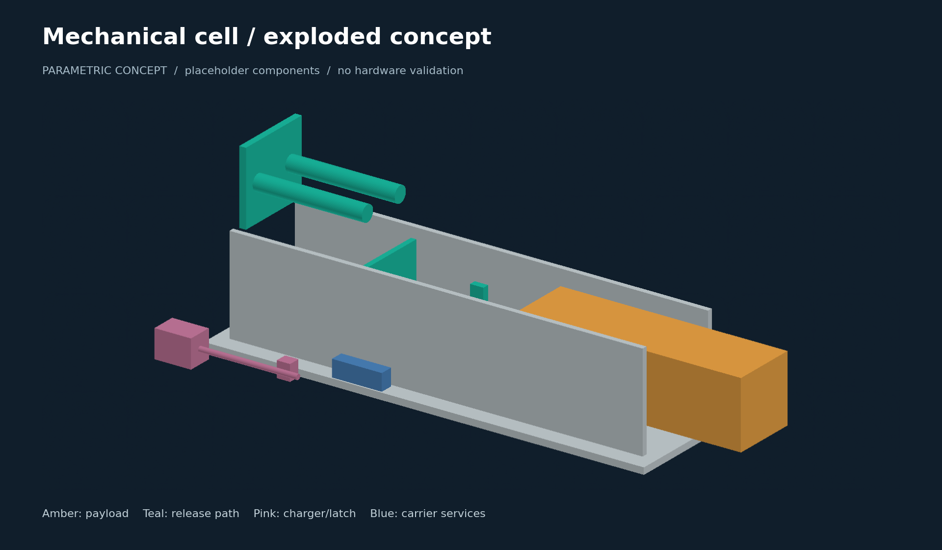
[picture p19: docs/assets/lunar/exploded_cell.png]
Current mechanical cell


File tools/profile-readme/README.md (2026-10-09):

# Adityavardhan Mishra

Mechanical engineering student · Spacecraft deployment, engines and systems software

BTech, Symbiosis Institute of Technology, Pune · 2023–2027

I like problems that survive the first calculation. My main project is **VOLLEY**, an investigation into controlled spacecraft departure from a retained orbital host. It began with a mechanism. The work since has been about finding out whether the mission earns that mechanism.

[Explore VOLLEY](https://aaaaaaaaaaaavm.github.io/VOLLEY/) · [Explore BOLLEY](https://aaaaaaaaaaaavm.github.io/VOLLEY/bolley.html) · [Engineering record](https://github.com/aaaaaaaaaaaavm/VOLLEY) · [Contact](mailto:adityavardhanmishr@gmail.com)

<p align="center">Four STEP-derived Blender views showing intended Gen5 operations; the evaluated reference fit and 3U mass criteria fail</p>

*The storyboard is conceptual motion from FreeCAD-linked STEP geometry, not a mechanism test. The current Gen5 academic evaluation fails its reference fit and 3U installed-mass criteria; final freeze is open. Nothing in VOLLEY or BOLLEY has been built, measured, qualified or flown. [Watch the eight-second Gen5 sequence](https://github.com/aaaaaaaaaaaavm/VOLLEY/blob/main/cad/renders/sequence/gen5_intended_sequence.mp4).*

## Start with the question, then inspect the evidence

| Project | What I am investigating | Useful starting point |
|---|---|---|
| **[VOLLEY](https://github.com/aaaaaaaaaaaavm/VOLLEY)** | Can provider-hosted control of release velocity, direction and timing earn its installed mass and operating burden? | [Current status](https://github.com/aaaaaaaaaaaavm/VOLLEY/blob/main/docs/NEXT_GENERATION_STATUS.md) |
| **[BOLLEY](https://github.com/aaaaaaaaaaaavm/BOLLEY)** | Does a passive spacecraft interface justify its mass by letting the launcher remove the moving sled and return mechanism? | [Selected winding and drive](https://github.com/aaaaaaaaaaaavm/BOLLEY/blob/main/docs/CURRENT_REVIEW.md) |
| **[GatewayCX](https://github.com/aaaaaaaaaaaavm/GatewayCX)** | How should ordinary network applications survive long delays and interrupted Earth–Moon links? | [Architecture and executable software evidence](https://github.com/aaaaaaaaaaaavm/GatewayCX#readme) |

## VOLLEY: evaluate one configuration, then decide what follows

Gen5 is the controlled computational configuration for academic review. Its historical periodic model returned **16.029 m/s at 10.07 g** and a **126.6 kg** modeled dry mass. A finite-geometry force screen challenges that speed with an ideal-phase **12.448 m/s** result; neither is a demonstrated release setting. The modeled **10.55 kg per 3U** fails the installed-mass screen, and the side-fed reference STEP assembly has an **11 mm width shortfall**. The final freeze remains open while these and other verification items are resolved or dispositioned.

**Gen6 is future scaling research toward a 1 km/s-class objective.** No mechanism, payload class or speed range is selected or validated. The independent motor-charged spring-cell bank and long gas guide remain unselected historical studies.

The mission work compares release authority with host manoeuvres and competent spring/timing alternatives. A historical two-payload screen found accepted cases under its assumptions, but the later matched twelve-shot reference does **not** close in any sampled case. Neither study establishes product value or a provider-approved mission.

What I want a reviewer to inspect:

- [The matched mission reference](https://github.com/aaaaaaaaaaaavm/VOLLEY/blob/main/docs/MATCHED_MISSION_REFERENCE.md): one declared host, payload and target compared across release concepts.
- [The open-problem register](https://github.com/aaaaaaaaaaaavm/VOLLEY/blob/main/OPEN_PROBLEMS.md): corrections and failed claims remain visible.
- [The evidence boundary](https://github.com/aaaaaaaaaaaavm/VOLLEY/blob/main/docs/PROVENANCE.md): model output, cross-checks, nominal CAD and missing measurement are kept distinct.
- [The reproduction route](https://github.com/aaaaaaaaaaaavm/VOLLEY/blob/main/docs/CONTRIBUTING.md): acceptance criteria before execution, source hashes and executable checks.

The host supplies navigation, attitude control and permitted manoeuvres. The deployer supplies a release condition. It does not provide continuing stationkeeping or collision avoidance after the spacecraft leaves.

## BOLLEY: test the neighbouring premise

<p align="center">BOLLEY Gen3 nominal Fluxrelay assembly</p>

BOLLEY gives the payload a modelled 0.37136 kg passive magnetic/copper interface while retaining the powered windings and electronics on the launcher. The current 4 kg reference duty is 11.8 m/s over 0.90 m at at most 8 g nominal.

The electrical partition moved from four turns at 380 A to twelve turns at 126.667 A. The first twelve-turn fit failed its copper-volume check; the failure is preserved. The later detailed winding passes its nominal CAD bands, while field distribution, hot switching, manufacturing tolerances and installed mass still need closure.

[Current BOLLEY evidence](https://github.com/aaaaaaaaaaaavm/BOLLEY/blob/main/docs/CURRENT_REVIEW.md) · [What remains unresolved](https://github.com/aaaaaaaaaaaavm/BOLLEY/blob/main/OPEN_PROBLEMS.md)

## Smaller tools extracted from the work

| Repository | Reusable capability |
|---|---|
| [Pulsed Linear Motor Design Lab](https://github.com/aaaaaaaaaaaavm/pulsed-linear-motor-design-lab) | Force, stroke, moving-mass and source-impedance screens |
| [Orbital Deployment Trade Study](https://github.com/aaaaaaaaaaaavm/orbital-deployment-trade-study) | Two-body release, recoil and phase-drift comparisons |
| [Engineering Evidence Toolkit](https://github.com/aaaaaaaaaaaavm/engineering-evidence-toolkit) | Source, result, link and artifact consistency checks |
| [constraint-floor](https://github.com/aaaaaaaaaaaavm/constraint-floor) | Requirement-attributed mass lower bounds |
| [parametric-cad-evidence-pipeline](https://github.com/aaaaaaaaaaaavm/parametric-cad-evidence-pipeline) | Parameter-to-artifact provenance and build manifests |
| [spacecraft-separation-dynamics](https://github.com/aaaaaaaaaaaavm/spacecraft-separation-dynamics) | Impulse, recoil, tip-off and internal-mass screens |
| [gatewaycx-bearer-sdk](https://github.com/aaaaaaaaaaaavm/gatewaycx-bearer-sdk) | Bearer adapters and conformance checks |
| [disruption-network-lab](https://github.com/aaaaaaaaaaaavm/disruption-network-lab) | Scheduled-contact delivery experiments |
| [scientific-run-registry](https://github.com/aaaaaaaaaaaavm/scientific-run-registry) | Content-addressed computational runs and lineage |

These are narrow tools with explicit assumptions. Software tests and model agreement do not establish hardware performance.

## Beyond the repositories

I contributed to Team THRUST's payload-deployment work for the payload that placed second in the SDL Payload Challenge at IREC 2025. I work on Formula Student powertrain, motorcycle engines and ECU calibration, and run Poona Motor Club. Reverse-engineering Powertronic's map format led me to build a dual-map editor.

My engineering work uses Python for numerics and traceability, parametric CAD, field and structural solvers, and independent checks of equations and units. [The skills evidence map](https://github.com/aaaaaaaaaaaavm/VOLLEY/blob/main/docs/SKILLS.md) points to the actual files.

[VOLLEY-paper](https://github.com/aaaaaaaaaaaavm/VOLLEY-paper) holds the standalone IEEE-formatted Gen5 manuscript and evidence package; it has not been submitted. [VOLLEY-thesis](https://github.com/aaaaaaaaaaaavm/VOLLEY-thesis) holds the standalone college review, report, presentation and local evidence. [VOLLEY-lab](https://github.com/aaaaaaaaaaaavm/VOLLEY-lab) preserves exploratory and rejected branches.

[adityavardhanmishr@gmail.com](mailto:adityavardhanmishr@gmail.com) · [LinkedIn](https://www.linkedin.com/in/adityavardhanmishra/) · Pune, India

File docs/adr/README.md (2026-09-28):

# Architecture Decision Records

Required by the Engineering Programme Dossier and the TRB prompt. One file per decision, in a
fixed shape, so a decision can be audited without reading a narrative.

[`../DECISION_LOG.md`](../DECISION_LOG.md) is not superseded. It is the readable history
and remains the better document for understanding *how the project got here*. These records are
the structured view: what was decided, what else was considered, what it costs, and how it gets
validated. Where an ADR has a Context section, that prose usually came from the decision log.

## Template

```
# ADR-NNN, title

Status · Date · Phase
## Context, the forces at play, including what was not known
## Decision, what was decided, stated flatly
## Alternatives, what else was considered, and why it lost
## Consequences, what this costs, including the bad parts
## Validation, how we would find out this was wrong
```

The Consequences and Validation sections are the ones that matter. A record listing only
benefits is advocacy, not a decision record, and one with no validation path violates dossier
§7, every feature needs a path toward validation.

## Index

| ADR | Decision | Status | Phase |
|---|---|---|---|
| [001](001-electromagnetic-deployment.md) | Electromagnetic deployment instead of a spring | Accepted | Concept |
| [002](002-host-is-a-spent-upper-stage.md) | Host is a spent upper stage, not a free-flyer | Accepted | Concept |
| [003](003-linear-synchronous-motor.md) | Linear synchronous motor, not a coilgun | Accepted | Load-bearing |
| [004](004-ironless-stator.md) | Ironless stator | Accepted | I |
| [005](005-eddy-brake-not-regeneration.md) | Eddy-current brake; sled energy is dissipated | Accepted | I |
| [006](006-magnets-ride-the-sled.md) | Magnets ride the sled; the CubeSat is unmodified | Accepted | Load-bearing |
| [007](007-dual-transverse-cassettes.md) | Dual transverse cassettes | Accepted | I |
| [008](008-retention-gate.md) | Retention gate separates preload from release | Accepted | I |
| [009](009-coast-and-trim.md) | Coast-and-trim release zone | Accepted | I |
| [010](010-host-agnostic-interface.md) | Host-agnostic four-item interface | Accepted | I |
| [011](011-publish-publicly.md) | Publish publicly, defects included | Accepted | I |
| [012](012-adopt-modelled-sled-mass.md) | Adopt the CAD-calculated 9.445 kg sled | Accepted | I |
| [013](013-drop-invariance-claim.md) | Drop the lifetime-ratio invariance claim | Accepted | I |
| [014](014-fleet-setpoint-below-ceiling.md) | Fleet setpoint at 98.2 % of the open-loop ceiling | Accepted | I |
| [015](015-derive-not-paste.md) | Derive coupled values; never paste them | Accepted | I |
| [016](016-reconstructed-history.md) | Reconstruct git history with labelled dates | Accepted | I |
| [017](017-four-repositories.md) | Four repositories, two of them generated | Accepted | I |
| [018](018-programme-name.md) | VOLLEY is the programme name; EMOCD_ remains the part prefix | Accepted | Programme |
| [019](019-gen4-open-assembly-before-export.md) | Keep Gen4 open assembly separate from the Phase I baseline | Accepted | Gen4 transition |
| [020](020-inter-shot-cadence.md) | The inter-shot cadence is 1200 s, closing P31 | Accepted | Load-bearing |
| [021](021-freeze-the-register.md) | Freeze the defect register; measurement takes priority | Accepted | I |
| [022](022-stator-segmented-not-block-commutated.md) | Winding segmented for fault isolation, driven as one; closes P29 | Accepted | I |
| [023](023-target-host-class.md) | Target host is a spent upper stage, not an ESPA-Grande port; closes P9 | Accepted | I |
| [024](024-last-mile-delivery-conops.md) | VOLLEY is a last-mile delivery vehicle; plane change excluded | Accepted | I |
| [025](025-fixed-cell-manifest.md) | One cell geometry with class-specific inserts, not a cassette per class | Accepted | I |
| [026](026-cad-built-from-parameters.md) | The CAD is generated from parameters, not drawn | Accepted | I |
| [027](027-designed-velocity-loop.md) | The velocity loop is designed against margins; closes P47 | Accepted | I |
| [028](028-no-latex-in-the-flagship.md) | No LaTeX in the flagship; the manuscript is authored in VOLLEY-paper | Accepted | I |
| [029](029-phase-one-closes-on-gen5.md) | Phase I closes on Gen5; historical study is the Phase II design target | Accepted | I |
| [030](030-apply-the-depth-resolved-thrust-constant.md) | Apply the depth-resolved K_t and the three decisions beside it; moves the baseline | Accepted | I |
| [031](031-four-repositories-not-two-phases.md) | Four repositories by role, replacing the two-phase model | Accepted |, |
| [032](032-legacy_study-stage-integrated-gas-store.md) | historical study is a stage-integrated, payload-direct, gas-driven deployer; supersedes the historical study of ADR-029 | Accepted |, |
| [033](033-legacy_study-trim-stage.md) | historical study gains a motor that steers rather than throws, adopted with its pulse store unweighed (P77) | Accepted | I |
| [034](034-legacy_study-long-stroke-design-point.md) | historical study's stroke becomes the host stage's whole 8.0 m, same velocity, half the acceleration, half the gas, and friction at 28.39 % of shot work (P78, P82, P83) | Accepted | I |
| [035](035-drive-tube-material.md) | The drive tube is hard-anodised aluminium and the piston matches it, closes P85, and forecloses steam | Accepted | I |
| [036](036-seal-specification-and-the-trim-stage.md) | The seal is specified at 17.8 N and the trim stage is suspended rather than built, closes P89, amends ADR-033, defers A66 | Accepted | I |
| [037](037-a66-band-one-was-unsatisfiable.md) | A66's first band was unsatisfiable by a correct implementation and is withdrawn rather than widened; band 1R replaces it | Accepted | I |

Every decision in `DECISION_LOG.md` appears above. ADRs 012-018 record decisions that were
never written down anywhere before.

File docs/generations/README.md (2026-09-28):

# The generation archive

> **Current status, 2026-09-28:** The gas-guide generation below is a retired architecture study. No next-generation architecture has been selected; see [current status](../NEXT_GENERATION_STATUS.md).

One file per CAD generation, to the same structure. Until 2026-08-16 this record was uneven:
Gen1, Gen3 existed only as sections inside `cad/CHANGELOG_CAD.md`, Gen4 had a status document of its
own, and Gen5 and the later gas-guide study had no
per-generation record at all, only the ADRs that adopted them.

Each file answers the same seven questions, so two generations can be read against each other:

1. What it is, and what it was for
2. Dates and status
3. What is committed to this repository, file by file
4. Where the source document lives, and whether it is here
5. The operating point it was built at
6. Known defects
7. Why it was superseded

## The six

| | | Committed | Source |
|---|---|---|---|
| [Gen1](GEN1.md) | the geometric ancestor | 11 STEP | Fusion, not in this repository |
| [Gen2](GEN2.md) | first structured revision | 9 STEP | Fusion, not in this repository |
| [Gen3](GEN3.md) | parameter-reconciled; the masses come from here | 10 STEP, 2 STL | Fusion, not in this repository |
| [Gen4](GEN4.md) | Fusion CAD design | none, P43 | Fusion source documents, not in this repository |
| [Gen5](GEN5.md) | the frozen baseline | 8 STEP, 8 STL | `cad/build_gen5.py`, in this repository |
| [Historical gas-guide study](LEGACY_STUDY.md) | retired architecture study | 6 STEP, 6 STL | `cad/build_legacy_study.py`, in this repository |

## The gap this table makes visible

No Fusion document is committed anywhere in this repository. Not one `.f3d`, for any of the
four generations built in Fusion. What exists for Gen1, Gen3 is STEP, which is a *result* of the
Fusion model and not the model; what exists for Gen4 is nothing at all.

That is a single point of failure outside version control. `cad/parameters.json` already warns
that Fusion user parameters are document-scoped and drift silently across documents, the
documents themselves are not in the repository to check that against. If the Fusion hub is lost,
Gen1 through Gen4 are lost with it, and only their exports survive.

Gen5 and historical study do not have this problem, and that is the whole argument of
[ADR-026](../adr/026-cad-built-from-parameters.md): their source is a script in this repository,
and the geometry is a function of a parameter file that is also here.

Recorded as [P74](../../OPEN_PROBLEMS.md). Closing it means exporting each Fusion document as
`.f3d` and committing it. That is a manual export nobody has done, and it cannot be done from
inside this repository.

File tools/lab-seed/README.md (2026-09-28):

# VOLLEY-lab

**The vault: ideas that never became a complete thing, and the measurement that stopped each one.**

Most projects delete the work that did not finish, and the reasoning goes with it. This is where
the VOLLEY programme keeps it instead — an architecture priced and declined, a scaling study
answering a question nobody has asked yet, a measurement that killed something.

**It is a vault rather than a graveyard, and the difference is that a vault is organised for
retrieval.**

<!-- PROGRAMME-HEADER-START -->
| Repository | Role | You are here |
|---|---|---|
| [VOLLEY](https://github.com/aaaaaaaaaaaavm/VOLLEY) | Main: the authoritative engineering record. Improved continuously |  |
| [VOLLEY-paper](https://github.com/aaaaaaaaaaaavm/VOLLEY-paper) | The concept at its most reliable, as an IEEE-formatted manuscript. **Frozen when published** |  |
| [VOLLEY-thesis](https://github.com/aaaaaaaaaaaavm/VOLLEY-thesis) | The same concept as a full submission. **Frozen when presented** |  |
| **[VOLLEY-lab](https://github.com/aaaaaaaaaaaavm/VOLLEY-lab)** | The vault: ideas that never became a complete thing, and why each stopped | ← |
<!-- PROGRAMME-HEADER-END -->

> **Nothing here should be cited.** No baseline, no stability promise, no acceptance bands.
> Numbers on these pages may be wrong, half-finished or abandoned mid-thought. The engineering
> record is [VOLLEY](https://github.com/aaaaaaaaaaaavm/VOLLEY), and where anything here disagrees
> with it, **it is right and this is not**.

## What this repository is for

**The main record stays clean because this exists.** A research track kept *inside* it is one
`git checkout` from becoming an edit to the record; a separate repository is a wall rather
than a line on the floor.

## The one rule

**Every entry states why it stopped.**

Not "deferred" — *why*, with the number that decided it. The rail-drive entry upstream carries
the transverse edge factor of **0.0253** that killed it, against the **0.55** it had been sized
on. PII-14 below carries the drivetrain inertia that eats its own gain. PII-19 carries the **11 %**
that made a whole architecture the wrong answer. **That is what makes this evidence rather than a
pile**, and it is the only rule here.

> ### Nine entries stopped together on 2026-08-14
>
> [ADR-032](https://github.com/aaaaaaaaaaaavm/VOLLEY/blob/main/docs/adr/032-legacy_study-stage-integrated-gas-store.md)
> made the payload accelerate directly, by gas, along a rail the spent stage provides — and
> **deleted the subsystem that nine vault entries improve.** No mover, so PII-1, PII-2, PII-17 and
> PII-18 have nothing to act on; no stator, so PII-3 and PII-12; no bank, so **PII-7**, which was
> P26, the largest live defect the project carried; no envelope and no track, so PII-4 and PII-11.
>
> **Not one was refuted.** Each is a correct optimisation of a part that stopped existing, and
> **PII-1's own arithmetic is why the mover went**. The full list is in the main repository's
> [`docs/VAULT.md`](https://github.com/aaaaaaaaaaaavm/VOLLEY/blob/main/docs/VAULT.md).
>
> **PII-8 gains.** Its hardest problem was airgap straightness over a deployed structure, and the
> new architecture has no airgap.

An entry without a reason is not deferred. It is abandoned with extra steps.

## What is here

Long-form entries live in this repository. The complete register — every entry, its status
and its entry criterion — is kept in the main repository so the numbering cannot fork:
**[`docs/VAULT.md`](https://github.com/aaaaaaaaaaaavm/VOLLEY/blob/main/docs/VAULT.md)**.

| | |
|---|---|
| [**PII-8** — VOLLEY as a free-flyer](PII-8_free_flyer.md) | A long deployed track and release at perigee reaches TLI and Mars-class C3 without exceeding CubeSat qualification. **Stopped by three problems named in the file**: airgap straightness at 0.7–2 ppm over a deployed structure, a 294 kJ shot against a bank that already fails at 2.88 kJ, and whether 25 g survives review as a *sustained* load |
| [**PII-9** — the lunar case](PII-9_lunar.md) | Where this technology has always belonged, and the mass driver it descends from. 1.33 MJ/kg to lunar orbit, so 15 kW launches a tonne a day. **Stopped by having no host**: it describes a different programme, not this one. The payload is ore, so the g-limit governing the whole design disappears |
| [**PII-11** — a deployable track, and the side-rail layout](PII-11_deployable_track.md) | A telescoping track long enough to accelerate *and* regeneratively arrest reaches **48 % electrical-to-payload efficiency**, deletes the eddy brake and stows inside the ESPA Grande envelope the main design misses by 44 %. The only option that improves velocity and envelope together. **Stopped by type, not by number**: a deployable structure is an architecture change however good its numbers are |
| [**PII-14** — a cable-driven gondola on a deployed truss](PII-14_cable_driven_gondola.md) | Propulsion off the vehicle onto a cable, energy from a flywheel. **Stopped by the assumption inside its own headline**: +49.7 % assumed a drivetrain with zero rotating inertia, and a real one gives +15 to +30 %, possibly zero — in exchange for deleting the linear synchronous motor and the 24 validations behind it. Its two dead ends are recorded too, because both will otherwise be re-proposed |
| [**PII-19** — the induction-drive historical study](PII-19_induction_drive_legacy_study.md) | A linear induction drive on a 0.25 kg passive plate instead of a 9.445 kg magnet sled. **It was the main repository's design target for one day.** **Stopped by attribution, not refutation**: A35 calculated the mover it optimises at **11 % of dry mass**, so the whole synthesis is a careful, banded, correct optimisation of the wrong term. Its nine computed bands stand |
| [`notes/`](notes/) | Unstructured, date-stamped, finished by nobody |

**PII-11 is the one that is hardest to leave shut**, because unlike the others it improves the
machine actually being built rather than describing a different one. That is exactly why it
needs a gate.

## How something leaves

| From → to | Condition |
|---|---|
| **vault → main** | Its acceptance bands were declared **before its script existed**, and run |
| **main → paper / thesis** | Stable, effective and reliable against the problem statement |
| **paper / thesis → frozen** | Presented or published |

**Nothing crosses upward on enthusiasm.** An item is promoted by meeting the criterion it was
given — written when it was deferred, not when it is reviewed, because a criterion written
afterwards is written by someone who already knows what they want the answer to be.

## What does not belong here

**Corrections.** If something in the main repository is *wrong*, fix it there. The distinction
is by type, not by convenience: a tedious bookkeeping error belongs upstream, and a fascinating
architecture belongs here.

## Adding an entry

Name it. State what it buys, with a number. Say why it is improvement rather than correction.
Then write its entry criterion **before you stop thinking about it** — and when it stops, write
down what stopped it.

## Licence

**CC BY 4.0** — full text in [`LICENSE`](LICENSE), attribution form in [`NOTICE`](NOTICE).
Attribution requires credit, a link to the licence, and **an indication of whether changes were
made**.

**Not retroactive:** snapshots taken before this change remain available under the MIT licence
they carried at the time, retained at [`LICENSE-MIT-superseded`](LICENSE-MIT-superseded).

This repository carries copies of VOLLEY analysis code under `reference/volley/`. CC BY 4.0 does
not license patent rights, which is why a patent-granting licence was not used here.

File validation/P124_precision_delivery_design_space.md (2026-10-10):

# P124 — precision-delivery design-space screen

**Result type:** exact ideal two-body orbital-energy conversion and minimum constant-acceleration stroke screen. This is a *requirements aid*, not a Gen5 rated-performance result or evidence of command precision.

The customer job is a specified payload state and tolerance at an agreed epoch. Release speed alone is not that service: host state, direction, recoil, navigation, timing, repeatability, collision avoidance and disposal matter. The table assumes a 450 km circular Earth orbit and a purely prograde *inertial* increment; a real commanded relative release needs host momentum and attitude treatment.

## Orbital state sets the speed and accuracy problem

| Ideal axis-rise target | Required inertial tangential increment | ±axis band | Smaller-side increment margin |
|--:|--:|--:|--:|
| 1.0 km | 0.559 m/s | ±0.1 km | 0.0559 m/s |
| 1.0 km | 0.559 m/s | ±1.0 km | 0.5592 m/s |
| 5.0 km | 2.795 m/s | ±0.1 km | 0.0558 m/s |
| 5.0 km | 2.795 m/s | ±1.0 km | 0.5584 m/s |
| 10.0 km | 5.585 m/s | ±0.1 km | 0.0557 m/s |
| 10.0 km | 5.585 m/s | ±1.0 km | 0.5573 m/s |
| 20.0 km | 11.149 m/s | ±0.1 km | 0.0555 m/s |
| 20.0 km | 11.149 m/s | ±1.0 km | 0.5553 m/s |
| 28.8 km | 16.029 m/s | ±0.1 km | 0.0554 m/s |
| 28.8 km | 16.029 m/s | ±1.0 km | 0.5535 m/s |
| 50.0 km | 27.720 m/s | ±0.1 km | 0.0549 m/s |
| 50.0 km | 27.720 m/s | ±1.0 km | 0.5493 m/s |

The margins above allocate the **entire** semimajor-axis error to velocity magnitude. A real requirement must split that budget among host navigation, release vector, speed, epoch, propagation and tracking. It must also specify along-track/plane/perigee tolerances; semimajor axis alone is not precision delivery.

## Stroke and payload-load screening

| Relative speed | Minimum mean acceleration over 1.3 m | Payload kinetic energy at 4 kg | Ideal stroke at 10 g |
|--:|--:|--:|--:|
| 2.500 m/s | 0.2 g | 12 J | 0.03 m |
| 5.000 m/s | 1.0 g | 50 J | 0.13 m |
| 12.448 m/s | 6.1 g | 310 J | 0.79 m |
| 16.029 m/s | 10.1 g | 514 J | 1.31 m |
| 20.000 m/s | 15.7 g | 800 J | 2.04 m |
| 50.000 m/s | 98.0 g | 5,000 J | 12.75 m |
| 1000.000 m/s | 39,219.9 g | 2,000,000 J | 5,098.58 m |

At the 1.3 m *full usable stroke* idealization, the 10 g ceiling permits only 15.97 m/s; actual profiles may peak higher. A 1 km/s release of an ordinary 4 kg 3U payload would require 39,220 g and 2.0 MJ payload kinetic energy over that stroke, or 5.10 km at 10 g. These are kinematic necessities; conversion losses, magnetic force and brake energy increase the system burden. A 1 km/s-class goal cannot be inherited as a credible first Gen6 prototype requirement for an ordinary 3U on the Gen5 stroke.

P118's 12.448 m/s finite-force value is an *ideal motor-energy conversion*, not a demonstrated relative command. If it were entirely inertial and prograde from the reference orbit, it would yield 22.34 km immediate semimajor-axis rise. Actual host recoil and preburn must be modeled before using that number in a mission.

The old 0.0274 m/s (3σ) simulated release dispersion would correspond to about 49.5 m of two-body axis halfwidth **only if** it transferred unchanged to the challenged 16.029 m/s point and all error were tangential. It has not been measured or transferred to P118, and does not establish payload delivery accuracy.

## Product and prototype decisions

1. Derive a first Gen6 prototype's speed *and accuracy* requirements from a named customer state, tolerance, payload acceleration limit and host/provider interface. Use a lower-speed 3U engineering demonstrator until those are known. Keep 1 km/s as a separate long-range, payload-specific research question with a new stroke and load architecture.
2. Set one common-epoch mission benchmark with springs plus competent host maneuvers and VOLLEY. Count installed mass, host resources and failures. The existing P123 one-event comparison is unfavorable to Gen5, and the sampled twelve-shot case does not close.
3. Verify commanded range, direction and repeatability with a selected drive and mechanisms model; then test a calibrated physical prototype. Analytic orbital sensitivity is a requirement generator, not a measurement.

Ideal load and speed design space

Reproduce with `python3 analysis/precision_delivery_design_space.py`; `--check` verifies the committed result and figure. The JSON contains the constants, assumptions and unrounded numbers.

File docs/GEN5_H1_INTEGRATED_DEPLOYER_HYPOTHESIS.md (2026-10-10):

# H1 — whole-system reassessment of a captive passive armature

**Status: unselected research hypothesis, 10 October 2026.** This is a proposed *reassessment* of [VOLLEY-lab PII-19](https://github.com/aaaaaaaaaaaavm/VOLLEY-lab/blob/main/PII-19_induction_drive_legacy_study.md) after the evaluated Gen5 snapshot. PII-19 already used a light captive passive plate and left the spacecraft unmodified. H1 asks whether coupling that old drive idea to a credible shared structure, feed and matched mission changes its whole-system result. It is neither a revised Gen5 performance claim nor the Gen6 1 km/s programme. No H1 CAD, drive rating, twelve-shot trajectory, supplier mass or hardware test exists. No mechanism or patent novelty is claimed.

## Why a motor improvement alone cannot solve the present problem

[P123](../validation/P123_gen5_one_event_mass_screen.md) found a 52.717 kg Gen5 penalty in a narrow one-event device-plus-fuel comparison. The [recomputed necessary bounds](../analysis/results/gen5_architecture_bounds.json) make the decision sharper:

| Same one-event reference | Device mass |
|:--|--:|
| Current modeled Gen5 | 126.562 kg |
| Parity at P118's **ideal** 12.448 m/s | at most 73.932 kg |
| Absolute parity even if a perfect release eliminates the host preburn | at most 74.659 kg |
| Current Gen5 deficit even against that absolute bound | at least 51.903 kg |

The absolute bound is just `D_new + 2 kg reserve <= 72 kg spring device + 4.659253 kg spring one-event fuel`. It assumes zero Gen5 propellant consumption, which is more generous than the current force model. Perfecting the motor changes the allowed dry device mass by only **0.727 kg** relative to the P118 ideal-speed parity figure. Thus a faster shot alone cannot fix this *specific* mass comparison. A different paid mission could change the comparison; it must be demonstrated with the same accounting boundary.

Even the absolute 74.659 kg parity mass is **6.222 kg per carried 3U**, well above the separate 2 kg/3U study economic screen (24 kg total for twelve). Passing canister-class parity and passing the study's economic screen are different decisions. Neither is met by current Gen5.

## Candidate architecture

Keep each CubeSat mechanically and electrically unmodified. Place the conductive secondary on a **captured, reusable carrier** that contacts the spacecraft through a defined standard-rail cradle. A segmented primary accelerates carrier plus spacecraft; a positive end stop and brake retain only the carrier while the spacecraft departs. Integrate the primary, guide and launch-load path into one host-mounted structural cassette instead of counting a separate 50.03 kg enclosure group plus a separate 9 kg bracket without examining shared load paths. The feed mechanism is **not selected**: a center lift and an in-line transfer remain geometry alternatives.

```mermaid
flowchart LR
    A[Restrained 3U payloads] --> B[Single-payload indexed handoff]
    B --> C[Captured passive armature carrier]
    C --> D[Segmented induction primary and guide]
    D --> E[Payload departs through controlled interface]
    D --> F[Carrier brake, containment and reset]
    G[Shared structural load path] --- A
    G --- D
    G --- F
```

This *would need to* attack several costs together: moving permanent magnets, motor copper outside the active zone, brake energy, duplicated enclosure structure and the side-fed width conflict. PII-19 already showed why reducing the mover alone is insufficient: it was about **11% of dry mass**, while the pulse chain survived. Its segmented drive also left a **30.1% peak-to-peak handover ripple against a 20% band**. H1 additionally faces induction heating, transient edge effects, peak electrical demand, carrier capture shock, field exposure, launch retention and host structural coupling. It cannot be selected from a sketch.

The reason to investigate moving mass is physical, not a predicted redesign result: at the P118 ideal 12.448 m/s, **each kilogram of carrier requires about 77.48 J of ideal kinetic energy and the same amount of arrest energy** if not regenerated. The current 9.445 kg modeled permanent-magnet sled therefore carries about 732 J of ideal kinetic energy at that speed. An H1 carrier has no proven mass; the 0.248 kg conductive plate in [A30](../validation/A30_rail_drive.md) is only an electromagnetic secondary, not a complete restrained, guided and captured carrier. [A31](../validation/A31_plate_drive_normal_force.md) analyzed a plate *on the spacecraft* under steady 2-D assumptions. Its speed and self-centering predictions cannot be transferred to this captive-carrier arrangement.

## What is already prior art

- [Zhao et al., 2022](https://www.mdpi.com/2072-4292/14/17/4205) studied a stacked CubeSat electromagnetic transfer and adjustable release prototype.
- [Feng et al., 2025](https://doi.org/10.1155/ijae/3000765) modeled an induction coilgun and orbital reachable domain.
- [US10538348B2](https://patents.google.com/patent/US10538348B2/en) describes captive satellite restraint and pusher elements; the presence of broad related claims prevents an unsupported novelty assertion here.
- [NASA's ST5 structural review](https://ntrs.nasa.gov/citations/20070016620) documents a multifunctional electronics enclosure and integrated deployment mechanism.
- VOLLEY's own [A30](../validation/A30_rail_drive.md) and [A31](../validation/A31_plate_drive_normal_force.md) already explored plate induction drive. H1's contribution, if one survives the evidence programme, would have to be a **specific validated system integration and trade**, not "electromagnetic deployment," "a pusher," or "a passive armature."
- [VOLLEY-lab PII-19](https://github.com/aaaaaaaaaaaavm/VOLLEY-lab/blob/main/PII-19_induction_drive_legacy_study.md) already proposed a deployer-owned passive plate shuttle, with no spacecraft modification. Its pulse source and installed-mass problem are direct antecedents and must not be hidden by calling H1 a new launcher.

This is an initial source screen, not a freedom-to-operate or exhaustive patent review. The IEEE paper should not describe H1 as a demonstrated invention.

## Hard selection gates

1. **Installed mass and interface:** one complete H1 CAD/BOM must include restraint, carrier, primary, bank, inverter, thermal hardware, harness, brake, mounting and any host reinforcement. Compare standalone and host-integrated accounting without removing mass from both columns. The one-event necessary condition is **at most 74.659 kg** regardless of ideal speed; **73.932 kg** is the stricter P118-speed parity value. A credible design needs margin below the applicable bound. The unchanged 2 kg/3U criterion still corresponds to **24 kg** total.
2. **Geometry and launch loads:** a controlled FreeCAD assembly and STEP set must fit all twelve 3U payloads in an explicitly surrogate or named host envelope, with full restraint, actuator swept solids, worst-case clearances, tolerances and load paths. The current 11 mm clash cannot be hidden by a rendered view.
3. **Electromagnetic and electrical closure:** run transient 3-D finite-width/entry/exit induction force and normal-load sweeps against an independent formulation; couple selected coil, switch, source and hot resistance to motion. Publish current, voltage, force, speed and heat with mesh/time-step convergence and uncertainty. A30/A31 steady 2-D rows are *inputs for falsification*, not H1 ratings.
4. **Release and reset:** model standard-rail contact, tip-off, magnetic exposure, carrier stop, repeated brake heat, jam and abort states. A failed carrier capture must not create an uncontrolled object.
5. **Mission value:** repeat the same twelve-payload target against a qualified spring-class deployment plus competent host manoeuvres. Include installed mass, fuel, pointing, operations, risk and disposal. If no complete mission and resource advantage closes, report H1 as a rejected candidate.

## Decision for the academic record

Freeze the *evaluated* Gen5 study with its failed criteria visible. H1 is a falsifiable successor hypothesis for VOLLEY-Lab, not a replacement for Gen5 results in the current college slides or IEEE draft. The defensible IEEE contribution today is the checked **system-level feasibility finding** and its necessary mass bound. H1 becomes a paper result only after its own geometry, circuit, contact and mission evidence exists.

Recompute the bound with `python3 analysis/gen5_architecture_bounds.py --check`. The input is the existing P123 JSON and Gen5 mass ledger; the output is [this numerical snapshot](../analysis/results/gen5_architecture_bounds.json). No part of the calculation validates H1 hardware.

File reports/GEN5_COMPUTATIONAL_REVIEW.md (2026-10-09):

---
title: "VOLLEY Gen5 — computational evidence review"
subtitle: "Fixed academic configuration and negative design findings"
author: "VOLLEY engineering record"
date: "9 October 2026"
header-includes:
  - \usepackage{graphicx}
---

# Abstract

Gen5 is a computational study of a sequential electromagnetic deployer for twelve 3U CubeSats. Its historical periodic-force model gives 16.029 m/s and 10.068 g, but a finite-array calculation challenges that speed; no current motor rating is selected. This report gathers the electromagnetic, power, dynamics, orbit, mass, CAD and mission evidence into a claim-by-claim review. It records decisive failures: 10.547 kg of modeled deployer per 3U customer fails two mass comparisons; a side-fed CAD reference arrangement has an 11 mm width shortfall and exact-solid interference; and no sampled twelve-shot option closes. An independent 2-D finite-element solve confirms the finite-stator trend; a separate depth-resolved 3-D numerical formulation reproduces 1.042 kJ ideal work under shared assumptions. Circuit and selected-hardware effects remain open. The immediate two-body orbit change has a Cartesian check for an assumed historical 16.029 m/s release; the 1.60 lifetime multiplier has no independent rerun at that input. **VOLLEY itself has no built, fired, measured, qualified or flown hardware**.

# 1. Configuration and evidence classes

**New finite-geometry disposition.** The historical 16.029 m/s rating in the table below assumes periodic force over the 1.3 m powered stroke. A [finite-array/stator 3-D analytic integration](../validation/P118_gen5_finite_force_map.md) gives 1.042 kJ ideal work and a 12.448 m/s geometry-only speed under optimal phase with circuit losses omitted. The modeled magnet array has no direct stator overlap after 1.066 m travel. This challenges the rated performance claim and is not an independent FEM or hardware validation. The [unselected R1 FreeCAD feeder candidate](../cad/FEEDER_CANDIDATE_R1.pdf) clears twelve scripted envelope routes in a widened 570 mm enclosure, but no actuator, restraint or revised installed-system budgets exist. A [matched reference mission](../docs/MATCHED_MISSION_REFERENCE.md) includes dispenser mass and host recoil; no sampled twelve-shot option closes. These findings have not been rolled into the original rated shot, mass or lifetime models.

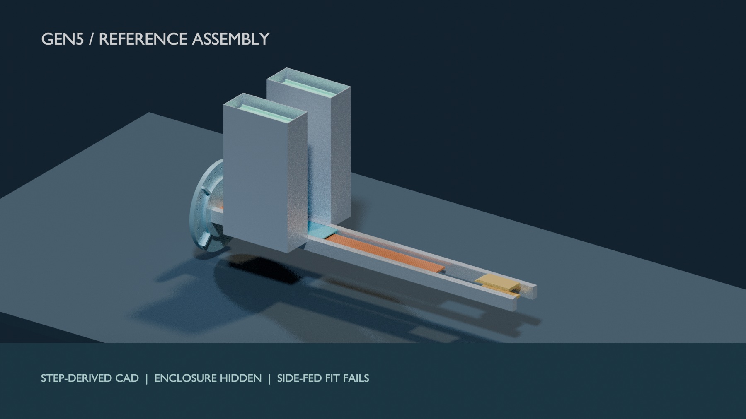
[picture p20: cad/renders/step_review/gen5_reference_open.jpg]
STEP-derived Gen5 reference assembly, enclosure hidden; reference placement has a known track/cassette clash.


*Figure: FreeCAD-linked STEP geometry visualized in Blender. The enclosure is hidden; this is neither photographed hardware nor a manufacturing release. [Source and image provenance](../cad/renders/step_review/README.md).*

Finite analytic force map

An [independent 2-D finite-element solve](../validation/P119_gen5_finite_force_fem2d.md) uses a vector-potential PDE, finite seven-wavelength arrays and the drawn 162-belt stator. Its 1 mm mesh gives **1,081.6 J ideal in-plane work**, compared with 1,041.7 J from the 3-D analytic screen. The 2-to-1 mm mesh change is 0.59%. This supports the end-of-stator force decline by a different field method; the 2-D solve omits magnet-depth end effects and is not a 3-D motor validation.

The [P121 independent depth-resolved 3-D surface-charge implementation](../validation/P121_gen5_finite_force_surface3d.md) calculates the full finite-depth cuboid field and integrates all 162 belts without calling the P118 field code. It finds **1,041.7 J ideal work**, agreeing with P118 to 4.35e-08%; face quadrature changes work by 0.00002% from 16 to 24 nodes and station refinement changes it by 0.096%. Seven independent air-field probes differ by at most 0.00002%. These close a numerical formulation check under shared magnetization, geometry and ideal-phase assumptions. They are not a 3-D FEM, a selected motor or measurement.

The [P122 deterministic sensitivity sweep](../validation/P122_gen5_finite_force_sensitivity.md) gives **906.7 J at 14 mm face gap** versus 1,041.7 J at 12 mm, a 13.0% ideal-work decrease. A 16 mm gap gives 789.9 J; a 10 mm copper depth offset gives 961.2 J. These are illustrative perturbations, not supplier or fabrication tolerances, and do not define an achievable release speed.

Independent depth-resolved force cross-check

Ideal finite-force geometry sensitivity

Independent 2-D finite-element force comparison

The [P120 finite-force shot rerun](../validation/P120_gen5_finite_coupled_shot.md) interpolates P118's position-dependent force through the assumed historical 96 V/6 F/12 mΩ bank and converter equations. With the full 1.3 m winding energized it gives **12.448 m/s and 2,098.6 J gross draw**; with a hypothetical 0.34 m active-copper length it gives **1,394.4 J** at the same ideal speed. Those two electrical branches are not selected hardware. The old 2.782 kJ, 47 J recovered, brake and dispersion results cannot be carried across without new models and interfaces.

Conditional finite-force shot histories

Matched reference mission

Unselected R1 geometry section

The [configuration index](../docs/GEN5_CONFIGURATION_INDEX.json) hashes the eight source STEP parts, the FreeCAD exports and native document, geometry parameters, governing model code and result files. Its status is `COMPUTATIONAL_DESIGN_REVIEW_CANDIDATE`; identity of files is not proof that an equation or material assumption is correct. The reference host is a 450 km circular orbit with a tangential prograde impulse for the orbital comparison, not a provider-approved mission. No named flight CubeSat, provider ICD or full installed system exists.

This report distinguishes **model output**, **independent numerical cross-check**, **prior-art support**, and **physical measurement**. The last class is empty for Gen5. A plot exported by a Python model is not a screenshot of a solver or an experimental trace. The CAD views are B-rep visualizations. The [figure evidence index](../docs/FIGURE_INDEX.md) and individual run sheets identify each image's source.

# 2. Historical machine and electrical result

| Quantity | Historical model value | Boundary |
|:--|--:|:--|
| Exit speed, 3U | 16.029 m/s | Historical periodic-model operating point, challenged by finite geometry |
| Peak acceleration | 10.068 g | Payload load not qualified |
| Gross / net electrical draw | 2782.391 / 2735.3 J | Coupled circuit/dynamics model |
| Net electrical-to-payload efficiency | 18.79% | Modeled recovery and losses |
| Closed-loop exit-speed dispersion | 0.0274 m/s, 3σ | Simulated sensor/uncertainty assumptions |
| Modeled dry / loaded mass | 126.6 / 174.6 kg | Assumed and geometry-derived lines mixed |

The shot trace below comes from `analysis/motor_model.py` and the checked-in model result. It is not an oscilloscope capture. The field plot is from the declared analytical field builder; P121 separately checks the ideal full-depth force integral under shared linear magnetic assumptions. Hot winding resistance, inverter switching, full bank supplier data and protection remain unresolved.

\begin{center}
\includegraphics[width=0.74\linewidth]{../figures/F01_shot.png}\\
\small Figure 1. Historical modeled shot profile; source: motor model, evidence class M.
\end{center}

\begin{center}
\includegraphics[width=0.73\linewidth]{../figures/A02_field_map.png}\\
\small Figure 2. Calculated Gen5 magnetic field; this does not measure integrated thrust.
\end{center}

A separate [historical energy and mass algebra audit](../validation/P117_rated_energy_mass_audit.md) reproduces the 4.000 kg/payload inference, 513.858 J payload kinetic energy, 1.30075 m constant-acceleration equivalent stroke, and rounded brake/recovery identities from the captured JSON. The old **124.488 J** compact-output remainder resolves into **90.964 J modeled converter loss, 32.460 J auxiliary draw and 1.064 J forward-Euler integration excess**, leaving less than 0.001 J after reported rounding. This closes the old model's arithmetic, not a supplier-backed source or a circuit-coupled finite-force shot.

# 3. Orbit, timing and complete-manifest checks

For a 450 km circular host reference, an **assumed historical 16.029 m/s** instantaneous tangential impulse gives a **28.800775 km** semi-major-axis rise in the [separate Cartesian DOP853 propagation](../validation/P115_rated_orbit_cartesian.md). The two-body numerical band is 0.02 m and passes. This confirms immediate orbital geometry for that assumed state. It does not independently establish the stated **1.60 lifetime multiplier**, which depends on a static atmosphere at mean activity and has no independent rerun at that input. It does not establish thrust, finite release duration or host acceptability.

\begin{center}
\includegraphics[width=0.78\linewidth]{../figures/rated_orbit_crosscheck.png}\\
\small Figure 3. Independent two-body geometry response; sweep points are not a Gen5 command envelope.
\end{center}

Timing alone from an unchanged host with zero relative release impulse creates no persistent same-epoch phase offset. The prior 468-second/30-degree claim is withdrawn. The six sampled finite-burn campaigns with a twelve-payload manifest return accepted prefixes of **0, 3, 4, 0, 4 and 5**; no sample delivers all twelve. These are bounded surrogate cases with assumed host thrust and rules, not a proof that no mission can close. Spring impulse, spring plus host manoeuvres, onboard propulsion and orbital transport still require matched provider/payload mission comparison.

# 4. Mass and CAD decision

The modeled dry mass is **126.6 kg**, including an A46 enclosure build-up, assumed components, and a 9.445 kg sled from historical Gen3 solid volumes. For twelve 3U payloads this is **10.547 kg per customer**. It misses the project's approximately 2 kg/customer economic screen and is **1.758 times** an approximate 6 kg/3U spring-canister comparator, outside a separate ±15% parity band. The 64-corner mass ledger's most favorable evaluated requirement-deletion case remains 88.67 kg. These comparisons are screening assumptions, not supplier quotes.

The [FreeCAD 1.0 CAD review](../cad/GEN5_CAD_REVIEW.pdf) releases a native `.FCStd` document, eight FreeCAD-exported STEP parts and a 20-instance assembly STEP. The side-fed reference placement fails: 526 mm internal width versus 537 mm for track and cassettes before clearance. Both CadQuery and FreeCAD find **32,915 mm³** exact-solid track/cassette overlap per side. The clash is left in the native project for inspection. It may be remedied only by a new feeder/enclosure configuration and renewed analysis; the existing design cannot be called mechanically complete.

\begin{center}
\includegraphics[height=0.38\textheight]{../figures/gen5_packaging_section.png}\\
\small Figure 4. Dimension-derived cross-section and exact-solid clash. Reference placement, not a production drawing.
\end{center}

# 5. Evidence closure and review decision

The [C-00–C-20 freeze register](../docs/GEN5_FREEZE_READINESS.md) is the authority for each unresolved question. A dated clean-snapshot gate run passed 148 tests and left tracked files clean; that gate does not rerun all native FEM, SPICE, GMAT or CAD studies, and companion files were unavailable inside that isolated snapshot. P121 checks the ideal full-depth force by a second numerical formulation; P115 and P116 reduce uncertainty on immediate two-body orbit geometry and expose a mechanical packaging failure. They do not close a selected bank/inverter, release contact, brake arrest/reset, moving-load structure, magnetic payload compatibility, thermal cycling, provider integration, disposal or complete mission delivery.

The college rubric calls for achievement of objectives, technical quality, validation, documentation and demonstration. It offers special recognition for a working prototype; it does not make a prototype a stated prerequisite for all 40 final marks. A professional final review should demonstrate the reproducible models and native CAD, show the failed criteria prominently, and explain what a later physical programme must measure. A literature analogy or polished render must not be described as a Gen5 physical validation.

**Release decision:** Gen5 is a documented computational design study with an unresolved internal performance discrepancy and negative 3U mass/fit findings. It is **not** a complete deployer product, a provider-approved flight design, or a final evidence freeze. Gen6's 1 km/s-class objective remains a distinct research direction; it cannot repair a failed Gen5 criterion by changing the label.

# Reproduce and audit

From a clean checkout, install the pinned or declared Python dependencies, run `./tools/verify_all.sh`, then inspect its report and the exact source/result hashes. Rebuild the new orbit figure with `python3 analysis/rated_orbit_independent.py`. Rebuild the Gen5 STEP parts with `python3 cad/build_gen5.py --check`, the reference assembly with `python3 cad/build_review_assembly.py`, and the native handover with `/usr/bin/python3 cad/freecad_export_review.py` on FreeCAD 1.0. See [P115](../validation/P115_rated_orbit_cartesian.md), [P116](../validation/P116_gen5_assembly_packaging.md), the [CAD PDF](../cad/GEN5_CAD_REVIEW.pdf) and the [market/customer audit](../MARKET_AND_CUSTOMER_FIT.md) for source-specific limits.

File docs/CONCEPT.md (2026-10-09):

# What VOLLEY actually is: a last-mile delivery vehicle, not a bigger spring

> **Historical architecture narrative.** The sections below preserve the earlier concept and its assumptions. For the current mission, reopened historical study selection and evidence boundaries, read [the front page](../README.md) and [project continuity](CONTINUITY.md). In particular, conventional release speeds can differ, host structure is not free installed hardware, and no primary-mission isolation or provider accommodation has been demonstrated.

> Nothing in this project has been built, fired, measured, qualified or flown, and no result
> here has been reviewed by a third party. Every number is a script output.

> ## Extended 2026-08-14 by [ADR-032](adr/032-legacy_study-stage-integrated-gas-store.md)
>
> This file already had the idea and stopped one step short of it. §2 argues that a spent
> stage is a waste rather than a necessity, and then treats it as a *host*, something VOLLEY is
> mounted on.
>
> ADR-032 takes the step: the stage is not merely the host, it is the machine. Its structure is
> the rail, its skin and avionics are the enclosure, and the deployer is what gets added,
> 11.45 kg of containment and about 3 kg of gas store.
>
> Read that as an integration change and not a mission change. The stage has been the
> *orbital delivery platform* since [ADR-002](adr/002-host-is-a-spent-upper-stage.md) in 2023,
> that is what makes this a last-mile programme and not a dispenser programme. What ADR-032
> changes is how much of the deployment hardware the stage supplies, and
> [`LINEAGE.md`](LINEAGE.md) keeps the two columns apart on purpose.
>
> Four constraints dissolve rather than improve: the 44 % envelope overrun (nothing is stowed), the
> deployable-structure precision that killed PII-8 and PII-11 (no airgap, so millimetres rather
> than ppm), the supercapacitor bank no supplier sells, and the acceleration length that
> capped velocity at 1.30 m.
>
> What it does not dissolve is that no launch provider has agreed to any of it. Everything
> below stands; the concept is the same and the vehicle it runs on has moved from *beside the
> stage* to *the stage*.

Written 2026-08-10. This repository has always described the machine and rarely the
concept. Every document opens with a linear synchronous motor and works outward, which is the
right order for an engineer and the wrong order for anyone asking why the thing should exist.

The idea came first and it is not about the motor.

---

## 1. The problem, in one sentence

A rideshare CubeSat does not choose its orbit. It inherits whoever paid for the launch.

The spring that ejects it delivers 1-2 m/s, sized to create clearance from the stage. That does
change the orbit, no impulse leaves one untouched, and at 2.5 m/s it extends orbital lifetime by
8.2 %, but by a margin small enough that the satellite stays, for mission purposes, where the
primary left it, and by the same margin for every satellite the deployer carries. Satellites
carrying propulsion can correct for this. About 222 of the 4,800+ catalogued nanosatellites do.
The rest go where the manifest put them and stay there.

That is not a deployment problem. It is a distribution problem, and a constellation is only a
constellation once its members are distributed.

## 2. The idea: the stage that was going to burn up anyway

A launch vehicle's upper stage does its job in about ten minutes and then becomes debris. It is
deorbited, or it is left to decay. Either way the mass, the structure, the attitude control and
the residual propellant are thrown away.

POEM is the proof that this is a waste rather than a necessity. It is a spent PSLV fourth
stage operated as a stabilised platform after its job is done, with power, navigation, attitude
thrusters and a controlled reentry at the end. The precedent for stage reuse is flown.

VOLLEY is what you put on it to make the reuse worth something.

> ### The concept, stated plainly
>
> After the primary payload separates, the spent stage stops being debris and becomes a
> last-mile delivery vehicle. It repositions on its own reaction-control system between
> deployments, altitude shell to altitude shell, and at each station VOLLEY fires satellites
> off it at individually commanded velocities. When the magazine is empty the stage makes its
> final burn and reenters.
>
> The satellites are never modified. Nothing is bolted to them, plated onto them, or wired into
> them. They arrive as they would have arrived at a spring, and they leave at a velocity chosen
> for each one.

This is the difference between a *deployer* and a *delivery vehicle*. A deployer releases
satellites where the host already is. A delivery vehicle takes them somewhere.

## 3. Two configurations

### 3.1 Hosted, VOLLEY on a spent stage

The stage is doing something it was going to do anyway: exist in orbit for a while and then
deorbit. VOLLEY converts that interval into deliveries.

| Phase | What happens |
|---|---|
| Primary separation | The stage's contracted job ends |
| Station 1 | Attitude hold; VOLLEY fires *n* satellites at commanded velocities |
| Reposition | RCS burn to the next altitude shell |
| Stations 2...*k* | Repeat until the magazine is empty |
| Disposal | Final burn, controlled reentry |

The economics of this are unusual and worth stating. The stage, its attitude control and its
disposal burn are all paid for by the primary mission. VOLLEY's marginal cost to the launch is
its own mass and the recharge feed. It is a payload that rides for the price of a payload and
delivers like a transfer vehicle over a narrow band.

### 3.2 Dedicated, VOLLEY as the whole payload

On a small launcher, VOLLEY *is* the mission. The vehicle's job is to put one 126.6 kg machine
into a parking orbit; the machine then distributes its manifest. There is no primary customer
whose orbit everyone else inherits, because there is no primary customer.

This is the configuration where the phrase that started the project applies most literally: the
launcher delivers the cannon, and the cannon delivers the satellites.

### 3.3 Two operating modes, and they cut across both configurations

Hosted and dedicated is *where* the machine sits. This is *when* it fires, and the difference
matters more to a customer than the configuration does.

| | Deploy-on-arrival | Loiter-and-distribute |
|---|---|---|
| What happens | All twelve out shortly after insertion, then disposal | The stage stays up, repositions between altitude shells on residual propellant, and fires at each station |
| What the customer buys | Twelve satellites in one orbit at commanded velocities | Twelve satellites across several orbits from one launch |
| What it asks of the stage | Minutes to hours of life past its contracted job | Weeks to months, and an owner willing to grant them |
| What ends it | The disposal burn | Drag, and see below |

Loiter-and-distribute is the mode this concept exists for, and it is the one
[ADR-002](adr/002-host-is-a-spent-upper-stage.md) pointed at in 2023 when it made the stage the
host rather than a free-flyer.

> The boundary on it is computed rather than assumed, and it is tighter than it looks.
>
> Altitude repositioning is cheap. Plane change is not, 133 m/s per degree, A15 band 8,
> against a whole shot of 16 m/s. The concept is altitude shells plus J2 doing the plane work over
> time, not a vehicle that flies to arbitrary orbits.
>
> And duration is bought with altitude. E28 found the fleet reenters in 29-36 days at
> 350 km, with only the 450 km case surviving 90.
>
> [A50](../validation/A50_campaign_altitude.md) modelled it on 2026-08-16. Satellite life is
> 476.6 days at 450 km, and walking three 50 km shells costs ~ 55 m/s, inside every host
> budget A20 swept. Days, weeks and months are all purchasable from 450 km upward, and orbital
> mechanics is not the constraint on loiter. The stage keep-alive agreement is.
>
> And E28's central trade turns out not to be one. Across 350 to 450 km the 90-day plane spread
> moves 47.1° to 44.6°, about 5 %, while satellite life changes by 6.7x. At the shell spacing
> this architecture uses, spread is nearly altitude-independent and life is not, so the design
> rule is simply to go higher.
>
> Read those durations as upper bounds. A50's decay model gives 70.6 days at 350 km against
> the 29-36 the GMAT runs observed, because `astro.py`'s atmosphere is static, P79. E28 stays
> open until the model is checked against a variable atmosphere.

## 4. What the concept can and cannot do, quantified

The honest boundary matters more than the pitch, and this project has already established
both halves of it.

| Manoeuvre | Cost | Available? |
|---|---|---|
| Altitude shell change, 50 km | 27.8 m/s, two-burn Hohmann at LEO | Yes, but it is a real propellant bill, see A20 |
| Phase / along-track spacing | free; it is what differential velocity produces | Yes, this is VOLLEY's own job |
| RAAN separation | free, over time, from differential J2 | Yes, A15 computed 367° of nodal spread in 90 days, in GMAT |
| Inclination change, 1° | 133 m/s, A15 band 8 | No. 8.1x VOLLEY's entire shot, and beyond a spent stage's RCS |

Plane change is not on the menu and this project says so everywhere. One shot spent entirely
on plane change buys 0.1229°, confirmed twice, once analytically and once in GMAT. Any
framing that implies orbit-plane selection is false.

What is on the menu is altitude, phase, and, given time, RAAN. The last one is the
interesting result: `validation/A15_poem_campaign.md` found that satellites left at different
semi-major axes decay at different rates, their nodes regress at different rates, and the spread
compounds. 367° of relative nodal position over 90 days, from a perturbation the deployer does
not control and does not pay for.

So the delivery envelope is: a set of altitude shells reachable by the stage's own RCS, a
commanded along-track distribution within each shell, and plane separation that develops for
free over the campaign. `validation/A20_reachable_envelope.md` quantifies it against a host Δv
budget.

## 5. Why this is not an orbital transfer vehicle, and should not claim to be

An OTV carries satellites to a destination using hundreds to thousands of m/s of propulsion. It
changes planes. It rendezvouses. VOLLEY does none of that and cannot.

The argument is right-sizing, not superiority. A constellation that needs its members spread
in phase and altitude does not need a spacecraft's worth of propulsion to do it, and an OTV
makes the customer buy exactly that, plus its mass, cost and schedule, with the Δv shared across
everything aboard. VOLLEY is sized for the job that is actually being asked for, and the job
is smaller than the tool the market currently offers for it.

`docs/LANDSCAPE.md` puts it correctly: not the same market.

## 6. Why not just use a spring

Because a spring gives every satellite the same push, and distribution requires a
*difference*.

| | Spring | VOLLEY |
|---|---|---|
| Velocity | 1-2 m/s, one value for every satellite | 16.029 m/s, commanded per cell |
| Designed differential between satellites | zero, any spread is manufacturing scatter | up to the full range, resolvable to 0.0274 m/s (3σ) |
| Orbital lifetime extension | +6.5 % at 2 m/s, +8.2 % at 2.5 m/s | +60.2 % |
| 30° of in-track phase | Waiting alone gives no persistent phase; a spring impulse or drag difference must be modeled | A 10 m/s relative-impulse model reaches about 30° in 1.4 days under its stated two-body assumptions; [timing-only correction](PHASING_CORRECTION_2026-10-09.md) |
| Deployer mass per 3U satellite | ~6 kg, canisterised class | 10.547 kg, VOLLEY loses, by 1.758x |

The lifetime figure is the one to read, not the velocity ratio. VOLLEY is 6.4x a spring on
raw Δv but 7.3-9.2x on what that Δv actually buys, because lifetime extension is superlinear
in this regime. And the differential row has no ratio at all: it is a capability springs do not
have, at any price.

> ### Mass parity is withdrawn, [P69](../OPEN_PROBLEMS.md)
>
> This section used to read *"Mass is at parity. That is the part that surprises people, a
> magazine-fed electromagnetic launcher lands in the same kilograms-per-satellite class as a
> canister of springs."* It does not. [A21](../validation/A21_comparators.md) band 4 asked for
> parity within 15 % and the measured ratio is 1.758: 10.547 kg per 3U satellite against a
> dispenser's ~6.0 kg. It failed on a change to *this* work rather than to the comparator,
> [A46](../validation/A46_enclosure_buildup.md) replaced an 8.00 kg packaging placeholder with
> 50.04 kg of derived line items, and no enclosure change reaches parity: the lightest
> alternative structure costed would give 8.87 kg per satellite, ratio 1.48, still failing.
>
> What survives the loss is the differential row, which is categorical rather than a ratio and
> which no mass correction touches.

> Where it loses, because a page that only argues one way is a brochure. A spring is TRL 9
> with thousands of deployments; VOLLEY is TRL 2-3 with nothing built or measured (E4). A
> spring asks its host for one deploy signal; VOLLEY asks for 150-300 W, a serial link and an
> authorised firing window. A spring has one failure mode; VOLLEY has a motor, a bank, a sled, an
> escapement and a gate. At 3U a customer who is willing to modify their satellite can fit a
> 0.5-1.2 kg cold-gas module and beat VOLLEY on mass by about 8x.

## 7. How the payload class changes the product

The argument is not the same at every size, and that is worth saying because the repository's
economics turn on it.

| Class | What the customer is buying |
|---|---|
| 3U / 6U | Per-satellite commanded velocity. Low count, high value each. Mass per satellite loses to a dispenser by 1.758x and to a propulsion module by 12.4x |
| 1U / PocketQube | Distribution at volume. Deployer mass per satellite falls by up to 30x, which is where the commercial argument actually closes |
| ChipSat / femtosat | A designed dispersion across a swarm. Individual velocity control stops being meaningful; what matters is the *shape* of the velocity distribution across hundreds of units, and no other deployer can produce one, because every alternative gives every unit the same push |

`docs/PAYLOAD_CLASSES.md` carries the numbers. The ladder is the strongest commercial argument in
the project and it is the least designed: until 2026-08 no cassette, cradle or gate existed for
any class except 3U.

---

## What this document is not

Evidence. Nothing here is measured. The concept rests on a machine that exists as models and
CAD, and `OPEN_PROBLEMS.md` lists what is still open about it. The delivery envelope in §4 is
computed from `analysis/astro.py`; the comparison in §6 from [`../validation/A21_comparators.md`](../validation/A21_comparators.md); the
plane-change ceiling from `validation/A15_poem_campaign.md`, which is the one row here an
independent propagator has confirmed.

What would have to happen before any of this flies is a build-readiness question, and it is
answered subsystem by subsystem in the Phase I close rather than here.

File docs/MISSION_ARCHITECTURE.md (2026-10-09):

# The mission VOLLEY actually flies

> **Historical architecture narrative.** The sections below preserve the earlier concept and its assumptions. For the current mission, reopened historical study selection and evidence boundaries, read [the front page](../README.md) and [project continuity](CONTINUITY.md). In particular, conventional release speeds can differ, host structure is not free installed hardware, and no primary-mission isolation or provider accommodation has been demonstrated.

Written 2026-08-22. The one-line description, *an electromagnetic CubeSat deployer*, has been
wrong since [ADR-032](adr/032-legacy_study-stage-integrated-gas-store.md), and the shorter it gets the
more wrong it is. This file is the operational concept, and it is the thing every other
document in the programme should be read against.

---

## 1. The problem, in one paragraph

A rideshare secondary inherits the orbit of whoever paid for the launch. It is placed where the
primary was going, at the time the primary was going there, with whatever separation velocity the
dispenser was built with, a few tenths of a metre per second, identical for every satellite in the
canister. A constellation operator who wants twelve satellites spread around a plane, or at two
altitudes, or phased apart, either buys a dedicated launch, or puts propulsion on every satellite,
or waits for differential drag to do it over months.

---

## 2. What VOLLEY is

VOLLEY flies as a secondary system integrated with the launch vehicle's final stage.

1. The vehicle flies its primary mission. Nothing about VOLLEY is in that path.
2. The primary spacecraft separates. The primary customer is served, and served first.
3. Only then does VOLLEY's mission begin. The spent stage is not released as debris at that
   moment. Where the vehicle architecture and the mission rules permit it, the stage stays
   powered, navigated, attitude-controlled and commandable, and becomes a temporary orbital
   delivery vehicle.
4. The stage repositions. VOLLEY releases. Coarse orbital placement is the stage's job; the
   commanded per-satellite separation velocity is VOLLEY's.
5. The stage disposes of itself. Passivation and re-entry, on reserve that was budgeted before
   the first satellite left.

> ### The division of labour is the whole architecture
>
> | | |
> |---|---|
> | HOST STAGE | coarse orbital repositioning, altitude, phase, orbital energy, over orbits to days |
> | VOLLEY | fine per-satellite release state, a commanded velocity, per satellite, in seconds |
>
> Neither half is interesting alone. A stage that repositions still drops every satellite at the
> same speed. A deployer with a commanded velocity still only ever launches from wherever the
> primary was going.

---

## 3. Three resources that are not the same thing

This distinction has been collapsed in casual descriptions of the concept and it must not be.

| | What it is | Whose it is |
|---|---|---|
| 1. Host-stage propulsion reserve | Propellant intentionally reserved for post-primary manoeuvres, or characterised residual a host can actually use. Main engine, auxiliary, RCS, it depends entirely on the vehicle | The launch provider's. VOLLEY does not own it and cannot assume it |
| 2. Host-stage attitude, navigation and power | What keeps the stage pointed, located, powered and commandable after passivation would normally have begun | The launch provider's, and A37 counts a stage kept alive as hardware that exists whether or not VOLLEY's rollup counts it |
| 3. VOLLEY's own deployment actuator | The historical study cold-gas system, 2.0 L at 22.7258 bar of nitrogen, a free piston, an 8.0 m bore, and the suspended trim stage | VOLLEY's. It is a different fluid system in a different pressure vessel and it never manoeuvres the stage |

Resource 3 produces the payload's local separation condition and nothing else. It cannot raise
an orbit, and 51.0 g of nitrogen per shot is not a propulsion budget.

---

## 4. Two operational modes

### 4.1 Rapid deployment

After primary separation the stage reaches a deployment attitude, VOLLEY fires the manifest over
a short period, each satellite receiving its own commanded velocity, and the mission ends in
passivation and disposal. Stage manoeuvres are minimal or absent.

*This is the mode that works on the widest range of hosts, and it is the one that survives if the
stage cannot restart.*

### 4.2 Distributed orbit delivery

The host stage retains a planned propulsion reserve, performs one or more manoeuvres across
multiple orbits, and VOLLEY deploys groups at the stage states it reaches. Different groups
reach different altitudes, phases and orbital energies. VOLLEY supplies the fine relative
velocity at each release.

What this mode may not claim. *Arbitrary plane changes.* They are priced below and they are
expensive.

---

## 5. Plane changes, priced

Derived here. Arithmetic shown, circular orbit, impulsive burn, `MU` and `RE` from
`analysis/astro.py`. Plane change: Δv = 2 v sin(Δi/2). Coplanar raise: two-impulse Hohmann.

| Altitude | Circular v | 1° plane change | 0.1° plane change | 10 km altitude raise, two-impulse total |
|---:|---:|---:|---:|---:|
| 350 km | 7697.0 m/s | 134.3 m/s | 13.4 m/s | 5.71 m/s |
| 500 km | 7612.6 m/s | 132.9 m/s | 13.3 m/s | 5.53 m/s |
| 700 km | 7504.3 m/s | 131.0 m/s | 13.1 m/s | 5.30 m/s |

> One degree of inclination costs about twenty-four times a ten-kilometre altitude change. The
> raise figure is the TOTAL of both Hohmann impulses, and at 500 km that total is two burns of
> about 2.76 m/s rather than one of 5.53. Quoting it as a single burn overstates the burn the
> engine has to command by about a factor of two, which is [P114](../OPEN_PROBLEMS.md).
> So the distributed mode delivers altitude, phase and orbital energy. It does not deliver
> planes, and any description of VOLLEY that implies otherwise is describing a different vehicle
> with a different propellant budget. *A tenth of a degree is affordable on a modest reserve; a
> degree is a mission of its own.*

**Correction 2026-10-09:** release timing alone is not free phase. Two payloads
released with zero relative impulse from an unchanged host remain in the same
two-body state. Spring impulse, host manoeuvre or differential drag can establish
a relative state, and a commanded impulse can change orbital energy. See the
[same-epoch calculation](PHASING_CORRECTION_2026-10-09.md). A full campaign
trade remains open.

---

## 6. Host classes

No launch provider has agreed to anything ([E5](../OPEN_PROBLEMS.md), and it is `HOST_DATA` in
[`COMPUTATIONAL_CLOSURE.md`](COMPUTATIONAL_CLOSURE.md)). So the product's dependency on the host is
made explicit as classes rather than hidden inside one assumed vehicle.

| | Class A | Class B | Class C |
|---|---|---|---|
| | Controlled spent upper stage kept alive as a platform | Restartable upper stage with a planned reserve | Non-restartable host |
| Attitude, navigation, power after primary | yes | yes | limited or none |
| Post-primary orbital manoeuvres | as reserve allows | planned, multiple | none |
| Rapid deployment | yes | yes | yes |
| Distributed delivery | limited by reserve | yes | no |
| Disposal | controlled or natural re-entry | controlled | natural |

The flown precedent for Class A is ISRO's use of spent PS4 stages as POEM orbital platforms.
What the public record establishes: stages have been reused as orbital platforms after the
primary satellite mission; POEM operations begin after satellite separation; attitude
control and navigation are retained; POEM-3 performed post-primary manoeuvres to approximately
350 km; and the stage re-entered rather than remaining as long-lived debris.

> The precedent is that a stage can be kept alive and used. It is not an endorsement, an
> agreement, or a statement that any provider will host this. *Evidence level: public programme
> record. VOLLEY has no relationship with any launch provider or space agency.*

Class C is not a failure case. It is where the majority of hosts probably sit, and VOLLEY
still works there, it delivers commanded per-satellite velocity from wherever the primary went,
which is a smaller product and a real one.

[`HOST_REFERENCE_CASES.md`](HOST_REFERENCE_CASES.md) is the method for mapping a real, publicly
documented propulsion architecture against these three classes, and the reference cases worked
under it. It uses public sources and declared assumptions only, and it closes nothing here: E5
stays open, and a reference case is a study rather than a compatibility finding.

---

## 7. The mission has to end

No architecture is allowed to spend the last kilogram of stage propellant on customers and then
omit disposal. A complete concept of operations includes:

| | Status |
|---|---|
| Disposal reserve, budgeted before the first release | Not modelled. It is an input to the mission planner that does not exist yet |
| Passivation of VOLLEY's own pressure system, venting the reservoir | Not designed. [E32](../OPEN_PROBLEMS.md) is the nearest live entry |
| Controlled or natural re-entry of the stage | Host-dependent, and a Class B property |
| Collision avoidance during the campaign | [E18](../OPEN_PROBLEMS.md): the conjunction covariance is invented and is a live computation item |
| Mission-duration limit | [E28](../OPEN_PROBLEMS.md): campaign life at a real deployment altitude is not modelled |
| Loss of stage control mid-campaign | [E30](../OPEN_PROBLEMS.md)'s forfeiture case, and A47 counts the stage as the one shared element the project cannot engineer around |

Five of those six are live register entries. *The end of the mission is the least modelled part
of it, and this file exists partly to say so in one place.*

---

## 8. What this file is not

It is not a claim that the machine works. historical study's exit attitude is not established
([P103](../OPEN_PROBLEMS.md)), its seal friction is unmeasured ([P67](../OPEN_PROBLEMS.md)), and
nothing in this project has been built, fired or measured, E4. It is a statement of what
is being designed, so that every other document can be read against a single description of the
mission rather than four different ones.

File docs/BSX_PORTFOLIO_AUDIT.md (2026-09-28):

# BSX repository audit, 2026-09-06

I audited the public portfolio against the current repository heads, with VOLLEY first. This is a record of what I checked, not a claim that every equation, dependency, source or hardware assumption is correct.

## Scope and evidence

| Repository | Checks and disposition |
|---|---|
| VOLLEY | Full local gate, 31 existing property/regression tests, result freshness, baseline and public claims. Repaired stale overview; reconciled four already-completed register entries; executed separately declared A24-R and A2-R. Gen5 has 11 computation items and three decisions left; historical study has 18 computation items. |
| VOLLEY-paper | Compared headline PDF values, checked page counts, corrected the abstract's acceleration wording and spring comparison, rebuilt Letter/A4 manuscripts, and regenerated the evidence payload. |
| VOLLEY-thesis | Same manuscript corrections and matching rebuilt PDF; regenerated the flagship evidence payload. |
| VOLLEY-lab | Repaired the route inventory for existing VLAB-B002/B003 entries; checked namespaces, links and generated figures. |
| BOLLEY | Repaired the stale result inventory and wired A9-A9f/A5f-A5h into the checker; executed A5h against its frozen bands; checked the four packaged CAD scopes, source/artifact hashes and injected failures. Nominal CAD only. |
| GatewayCX | 123 existing tests pass, including restart persistence, independent adapter, authenticated RPC and integrated replay. No new network interoperability claim is made by this audit. |
| engineering-evidence-toolkit | Six tests and repository verification pass: source hashes, finite result values and public links. |
| pulsed-linear-motor-design-lab | Seven tests and repository verification pass. Imported numerical reference evidence retains its original scope. |
| orbital-deployment-trade-study | Nine tests and repository verification pass. These are preliminary orbital and disturbance screens. |
| constraint-floor | Two existing tests pass. The additive attribution bound does not prove an optimum across all possible architectures. |
| spacecraft-separation-dynamics | Four tests pass after correcting apsis ordering for a direction-reversing impulse. |
| parametric-cad-evidence-pipeline | Four tests pass after adding parameter-digest, manifest-section, size and path-containment checks. |
| gatewaycx-bearer-sdk | Three tests pass after fitting the nominal conformance probe to small MTUs and rejecting invalid MTU types. |
| disruption-network-lab | Four tests pass after rejecting non-finite contact times and non-integral byte counts. The contact model still assumes no serialisation duration. |
| scientific-run-registry | Two existing tests pass for content-addressing and tamper detection. Concurrent writers were not exercised; this is not a transactional database. |
| aaaaaaaaaaaavm | Reconciled the spring comparison and linked the current review; kept the flagship profile template identical. |

Private non-portfolio repositories were inventoried through the connected account but were not included in the public code verification above. An empty repository has no executable material to verify.

## What closed and what did not

P37, P46, E29 and P95 had closing evidence already in the record; their dispositions were stale. A24-R newly closes P54's reference-literal defect while preserving original A24 failures. A2-R newly closes P55's depth-resolved lever computation. Neither changes the Gen5 operating point or the failed mass criterion.

A5h closes the declared nominal winding-CAD question only. Electrical implementation, packaged mass, switching losses, manufacturing details and hardware qualification remain separate BOLLEY tasks.

The remaining calculations, measurements, provider data and decisions are in [BSX_REVIEW.md](BSX_REVIEW.md). That generated list is the current handoff, and the repository gates require it to agree with the register.

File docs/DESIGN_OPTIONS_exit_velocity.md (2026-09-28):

> Updated 2026-09-06 by [A2-R](../validation/A2R_depth_resolved_levers.md): the current generated table uses separately integrated depth-resolved constants for all four magnetic geometries. The earlier discussion below is retained as design history; it must not supply a competing current operating point.

# Design options: recovering exit velocity

Status: exploration, not a result. Every row below drives `analysis/motor_model.py` with
modified inputs, the repo's own field model and shot integrator, no new physics. Nothing here
has been adopted and no baseline value has changed.

> Read [`VELOCITY_CEILING.md`](VELOCITY_CEILING.md) first. Every lever below moves the design
> toward a ceiling of 25.3 m/s set by this design's chosen 25 g acceleration limit over the 1.30 m zone (P98). Only stroke
> length moves the ceiling itself, and only the momentum-transfer release gets round it.

## The problem

P15: the Gen3 sled computed from CAD solid volumes is 9.445 kg, against the 4.86 kg
`motor_model.py` used to assume. At that mass the same machine delivered 16.03 m/s against the headline 20.37, and the
2026-08-03 quadrature correction has since moved it to 16.39 m/s.

## What each lever actually buys

> Generated by `analysis/velocity_levers.py`, re-run 2026-07-31. The table was hand-computed
> on 2026-07-28 and carried no current, no current density and no bank column, because no script
> modelled the bank's series resistance yet. Efficiency is now quoted net of regeneration
> (A11), which is why every row reads higher than it did.

Target 20.37 m/s. Sled mass 9.445 kg unless stated. `Kt` recomputed from the repo's field model
wherever the magnetic geometry changes.

<!-- LEVER-TABLE-START -->

| Lever | Sled | K<sub>t</sub> | K | Stroke | Exit velocity | J | Peak A | Efficiency | Bank ESR ceiling |
|---|---|---|---|---|---|---|---|---|---|
| Superseded 4.86 kg assumption | 4.86 kg | 10.54 | 140 | 1.30 m | **19.74 m/s** | 21.0 | 381 | 30.3 % | 61 mohm |
| As drawn (the baseline) | 9.45 kg | 10.54 | 140 | 1.30 m | **16.03 m/s** | 21.0 | 320 | 18.8 % | 72 mohm |
| Pocket 40 % of the titanium | 7.50 kg | 10.54 | 140 | 1.30 m | **17.33 m/s** | 21.0 | 341 | 22.5 % | 68 mohm |
| Pocket 60 % (aggressive) | 6.53 kg | 10.54 | 140 | 1.30 m | **18.11 m/s** | 21.0 | 354 | 24.9 % | 66 mohm |
| Magnets 8 to 6 mm | 8.53 kg | 8.87 | 140 | 1.30 m | **15.22 m/s** | 21.0 | 265 | 18.7 % | 87 mohm |
| Magnets 8 to 5 mm | 8.07 kg | 7.85 | 140 | 1.30 m | **14.59 m/s** | 21.0 | 232 | 18.2 % | 99 mohm |
| Raise sheet current to 213 kA/m | 9.45 kg | 10.54 | 213 | 1.30 m | **19.76 m/s** | 31.9 | 686 | 17.0 % | 34 mohm |
| Lengthen the stroke to 1.97 m | 9.45 kg | 10.54 | 140 | 1.97 m | **19.72 m/s** | 21.0 | 433 | 17.2 % | 51 mohm |
| Two-layer stator (G3-D4) | 9.45 kg | 6.63 | 280 | 1.30 m | **17.97 m/s** | 21.0 | 512 | 16.3 % | 45 mohm |
| Two-layer + 40 % pocketing | 7.50 kg | 6.63 | 280 | 1.30 m | **19.43 m/s** | 21.0 | 545 | 19.6 % | 42 mohm |

<!-- LEVER-TABLE-END -->

### The column that was missing, and it changes the ranking

Bank ESR ceiling is the highest series resistance at which the shot still completes. It is
not an efficiency target: a source of EMF `V` behind resistance `R` cannot deliver more than
`V^2/4R` into any load, so a lever that raises peak current *lowers* the resistance the bank is
permitted to have. A10 established this and P26 is the open defect.

A single commercial string of 32 x 190 F cells is 116 to 185 mohm. No row in the table clears
it. Not one. The as-drawn baseline needs 66 mohm, and every lever that buys velocity needs less:

| | Peak current | ESR ceiling | Parallel strings needed (PII-7) |
|---|---|---|---|
| As drawn | 347 A | 66 mohm | 3, and 4 with margin |
| Pocket 60 % | 385 A | 60 mohm | 3 to 4 |
| Lengthen the stroke | 470 A | 47 mohm | 4 |
| Two-layer stator | 597 A | 39 mohm | 4, no margin |
| Two-layer + 40 % pocketing | 637 A | 36 mohm | 4 to 6 |
| Raise sheet current to 213 kA/m | 749 A | 31 mohm | 6 |

So the ranking inverts. The two rows that looked best electromagnetically, two-layer and
raised sheet current, are the two that make the bank hardest to buy, and the bank is already the
largest open defect in the project. PII-3 is now explicitly gated behind PII-7: a two-layer
stator cannot be evaluated before a bank that can source it exists, and `docs/VAULT.md` says
so at PII-3's entry criterion.

The one row that gets *easier* on the bank is thinning the magnets, which reaches 95 mohm, and
it is also the row that goes backwards on velocity. Nothing is free in the direction anyone wants.

### A lever that is not in the table because it is not a lever

Block-commutating the stator. Every row above assumes the whole 1.30 m winding is energised
for the whole stroke, because that is what `motor_model.shot()` computes. If the winding is
driven segment by segment, energising the 340 mm under the sled, copper loss falls from
828 J to about 217 J, efficiency rises from 21.2 % to about 24.4 %, peak current falls
347 to 296 A, and the bank ESR ceiling rises 66 to about 79 mohm.

That is a bigger efficiency gain than any row in the table, and it costs nothing, which is why it
is not listed as an option. It is either already true and mis-modelled, or a real design choice
nobody has recorded. Logged as P29, because it is a question about the machine as built
rather than a proposal.
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

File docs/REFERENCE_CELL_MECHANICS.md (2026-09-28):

# Reference-cell spring, pusher and catcher screen

I evaluate a linear unloading spring at the S4 study point. No spring, latch, motor or damper is selected. P92 remains open.

**48 of 144 declared mechanical cases meet the analytical 10 g/contact screen.** Numerical verification: **PASS**.

The relative-speed study point is 4.569852 m/s for 4 kg. With zero friction and zero end preload, the spring requires at least **213.0 mm**, twice the **106.5 mm** constant-force ideal. Calling 106.5 mm a spring design would miss that distinction.
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

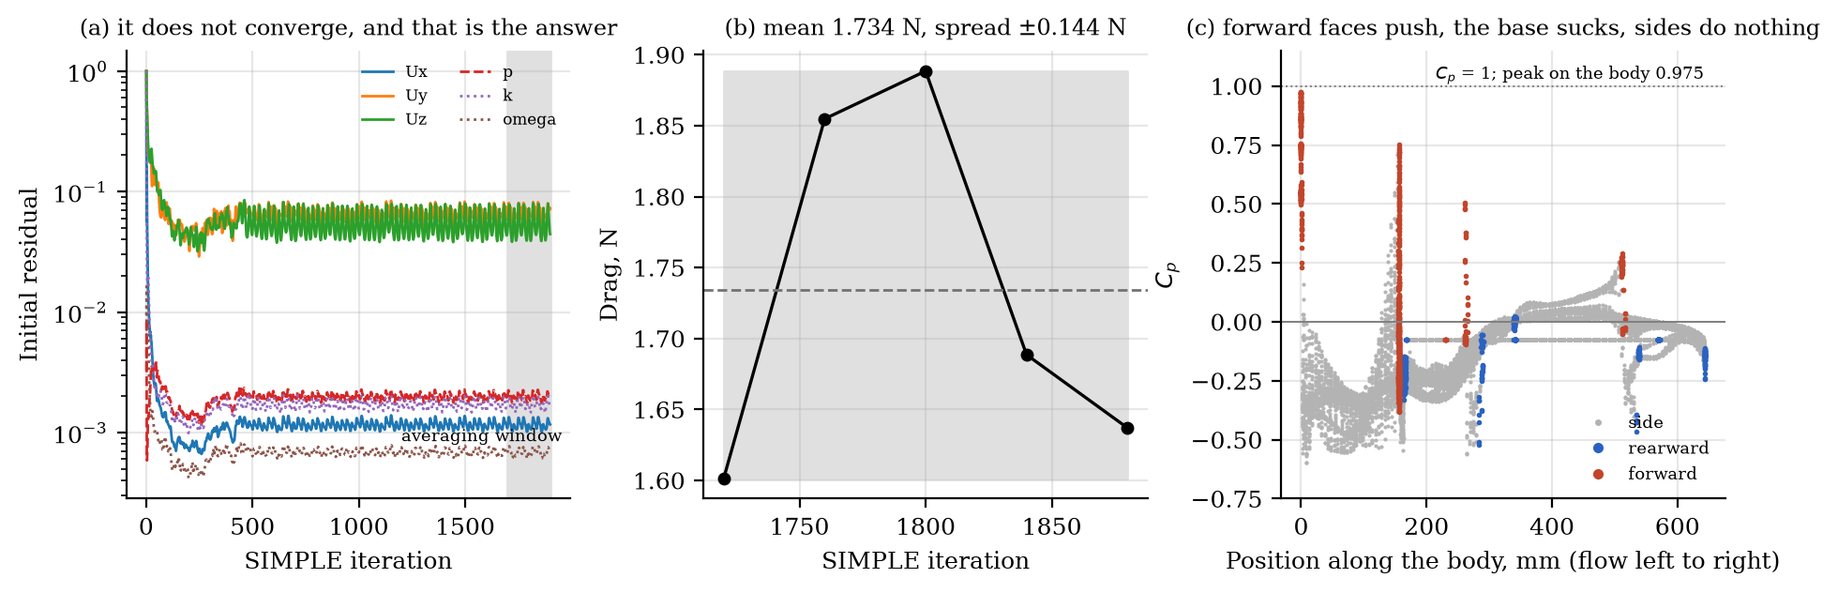
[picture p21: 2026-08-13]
figures/A29_cfd_report.png

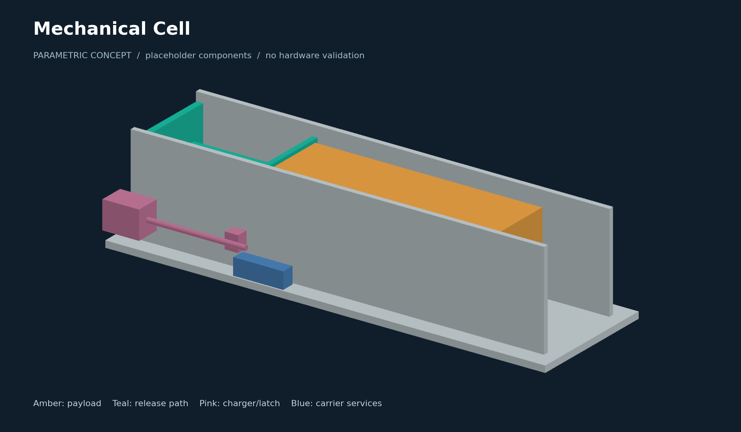
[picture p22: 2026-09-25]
docs/assets/lunar/mechanical_cell.png

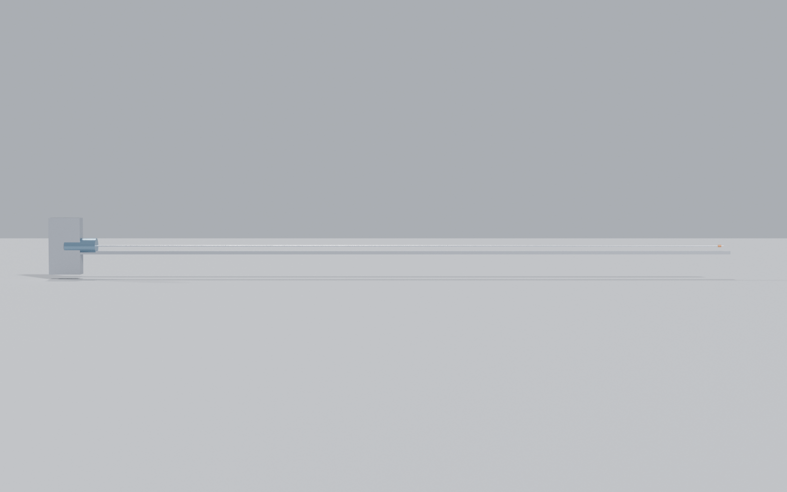
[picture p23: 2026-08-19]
cad/renders/gen6/side.png

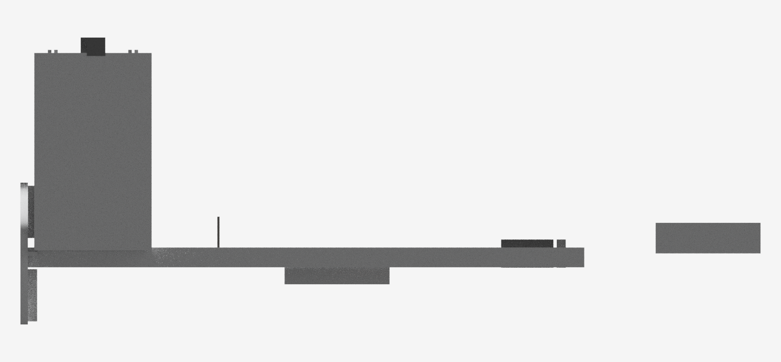
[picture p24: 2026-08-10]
cad/renders/source/track_stator.png

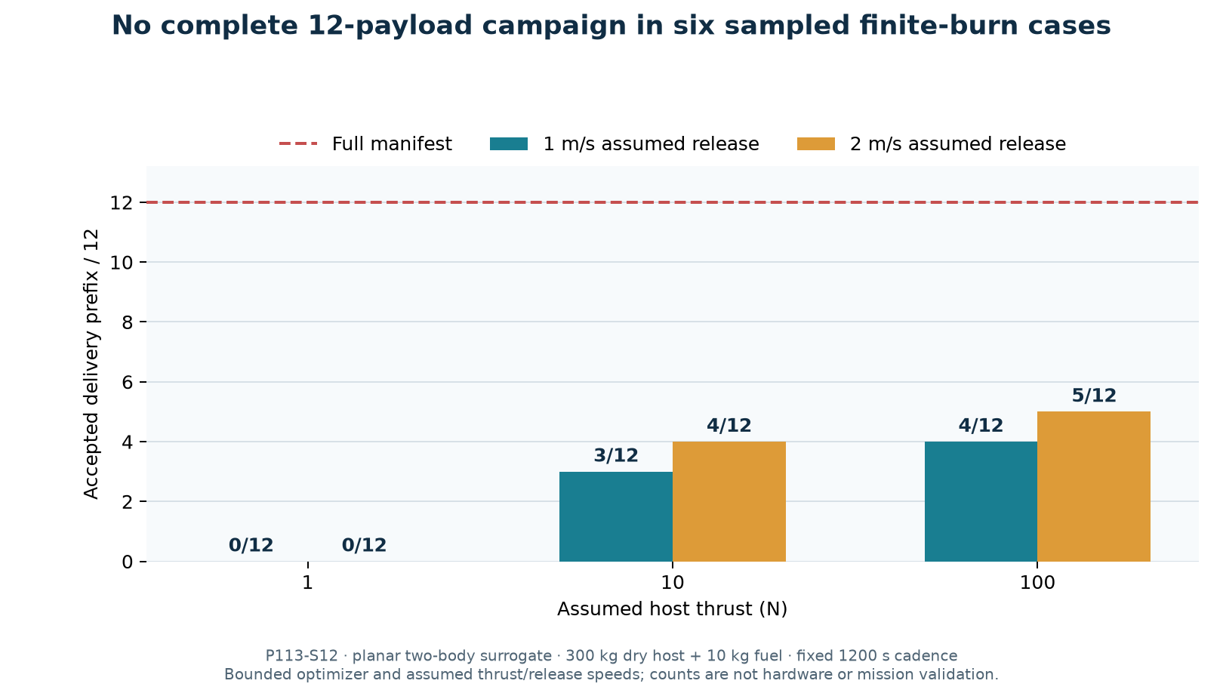
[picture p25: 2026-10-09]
figures/manifest_finite_burn.png

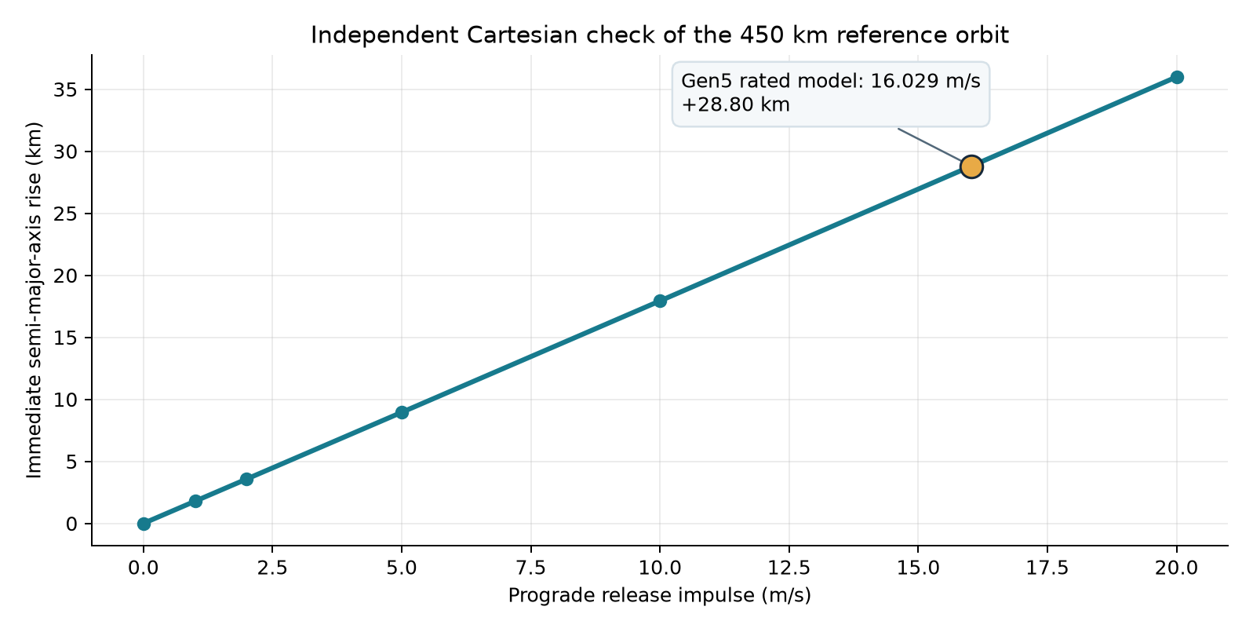
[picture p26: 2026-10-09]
figures/rated_orbit_crosscheck.png

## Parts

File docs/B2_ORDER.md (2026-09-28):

# B-2: the seal friction order

Written 2026-08-22. [`B1_ORDER.md`](B1_ORDER.md) is the order for the field measurement.
This is the order for the other one, the seal friction that
[P67](../OPEN_PROBLEMS.md) has made the single highest-leverage unknown in the programme.

> Why this exists as an order rather than a procedure. B-1 had a method since 2026-07-29 and a
> bill of materials since 2026-07-30, and was not ordered for six weeks. *A procedure invites more
> analysis. A purchase order invites a purchase.* This file is written the same way and for the
> same reason.

What it changes. [ADR-036](adr/036-seal-specification-and-the-trim-stage.md) suspended a
subsystem rather than guess this number. Five decisions wait on it, and it is the only
measurement in the programme that can *delete* work rather than add it.

| Measured friction | Consequence |
|---|---|
| <= 17.8 N | P88 closes, the trim stator is unnecessary, ADR-033 is amended out, and A66 is never written |
| 17.8,  22.3 N | The stator is still unnecessary, but the seal does not survive its own heat, P88 stays open |
| > 22.3 N | The stator is needed. ADR-036 falsifier 1 fires, ADR-033 stands, and A66/P92 becomes the next run with nothing in front of it |

The threshold is coarse, and that is the good news. This is not a precision measurement. It
asks which side of 17.8 N and 22.3 N a number falls on, and the current published
dispersion descends from an *allowance* of 83.4 N, 4.68x the specification. A crude test
discriminates.

---

## 1. What to buy

Total envelope: ₹8,000,  ₹26,000. Every figure is an estimate, not a quotation, and no
line item here has been priced by a supplier. `analysis/cost.py` carries no quotation either
(E16); this file does not change that.

### 1.1 The cylinder, buy the stock bore, and this is already settled

A pneumatic cylinder to ISO 6432, 16 mm bore, >= 100 mm stroke, spring-return or double-acting.

[A61](../validation/A61_seal_class.md) band 7 already checked that this substitution is free.
The design draws 15.805 mm; the ISO 6432 stock size is 16.000 mm; the shift in the required
friction fraction is 0.00 %. *The bore does not need to be special and buying a special one
would be the expensive mistake.*

- Seal type matters more than the cylinder. Ask the supplier which seal is fitted. The class
  the design assumes is spring-energised graphite-filled PTFE; ordinary nitrile is a different
  material with different breakaway behaviour, and a nitrile result does not answer P67.
- Buy three, not one. Shot-to-shot spread is half the question, P67 asks for
  *"a measured or supplier-bounded seal friction, with a shot-to-shot spread"*, and
  unit-to-unit spread is the cheaper half of it.
- Estimated ₹1,500,  ₹4,000 for three.

> ### CORRECTED 2026-08-22, before anything is bought: double-acting only, and the rig measures more than the seal
>
> This section said "spring-return or double-acting". Spring-return is now excluded, and the
> reason is arithmetic. A return spring on a 16 mm-bore cylinder develops a force of the same
> order as the whole of the 17.8352 N threshold, varying with position, and a quasi-static
> pull cannot separate it from friction without characterising it first. *It is a second unknown
> introduced into a measurement whose entire purpose is to resolve a decision window under 4.5 N
> wide.* Double-acting, no spring, both ports open to ambient unless band 7 pressurises one.
>
> And the deeper point, which the first version of this order did not state. VOLLEY's historical study
> interface is a free piston in a bore. [ADR-035](adr/035-drive-tube-material.md) records that
> the carriage is not recovered and that every seal makes exactly one 8.0 m pass, so the
> machine has one dynamic seal and nothing else in the force path: no rod, no rod seal, no
> wiper, no rod bearing.
>
> A stock cylinder has all four. A load cell on the rod measures piston seal plus rod seal
> plus wiper plus rod bearing, and on a 16 mm bore those three parasitic terms are
> plausibly of the same order as the gap between the two thresholds this order exists to
> resolve, 17.8352 N and 22.294 N. Sensor resolution does not touch this. A gauge good
> to ±1 N measures the wrong quantity to ±1 N.
>
> The fix is bands 13 and 14 below, not a caveat. The stock cylinder is retained because
> [A61](../validation/A61_seal_class.md) band 7 already showed the bore substitution is free and
> because a bespoke free-piston fixture is not a ₹8,000 item, but what it delivers is the
> *difference* between two configurations of the same hardware, not a load-cell reading.

### 1.2 The instrument, the binding requirement is sample rate, not accuracy

A load cell or force gauge reading to at least 50 N, logging at >= 500 Hz.

Accuracy is not the constraint. The thresholds are 17.8 and 22.3 N and the allowance is
83.4 N; a gauge good to ±1 N resolves all three comfortably. What matters is capturing
*breakaway* separately from *running* friction, and breakaway is a transient, a 1 Hz handheld
gauge will report neither.

- A logging load cell with a USB or serial output, ₹4,000,  ₹15,000.
- A crank-driven or dropped-mass pull is acceptable. A servo test stand is not required and
  buying one would be the second expensive mistake.
- Estimated ₹4,000,  ₹15,000.

### 1.3 Fixture and consumables

Rod-end clevis, a rigid mount, the lubricant the supplier specifies (and a dry sample: space
seals are not oiled), and a dial indicator for stroke position. ₹2,500,  ₹7,000.

---

## 2. The measurement, and the bands

> ## THESE BANDS ARE DECLARED BEFORE THE CYLINDER IS ORDERED, 2026-08-22.
>
> The same rule as every run sheet in `validation/`: the acceptance criteria are committed
> before the data exists. No band may be widened after a result is known. A measurement whose
> criteria are chosen after seeing the number is worth what an analysis with the same habit is
> worth, which is nothing.

| # | Question | Band | What a miss means |
|---|---|---|---|
| 1 | Breakaway friction, dry, at ambient, three units | report; >= 3 units, >= 10 pulls each | A single pull is an anecdote. The spread is the deliverable |
| 2 | Running friction over the stroke, same units | report, with the 3σ spread | This is the term A44 found carries 93.4 % of historical study's dispersion variance |
| 3 | Which side of 17.8 N the running friction falls | decides ADR-036 | *This is the whole purpose.* It is a discrimination, not a value |
| 4 | Which side of 22.3 N | decides whether A66 is ever written | See the table above |
| 5 | Unit-to-unit spread <= 20 % of the mean | <= 20 % | A44 swept ±20 % of the allowance and got 0.3115 m/s at 3σ. Above 20 % the dispersion claim is worse than modelled |
| 6 | Speed dependence across the achievable range | report the trend and the range tested | The design's mean piston speed is 17.1 m/s and its peak is 34.3 m/s. A bench pull will not reach either. Band 8 is why this is still worth doing |
| 7 | Ambient against the design's 22.73 bar side load | report; state whether the rig pressurised | Friction rises with the pressure that loads the seal against the bore. An unpressurised pull is a lower bound, and must be reported as one |
| 8 | Does this measurement discriminate, or only bound? | state the answer explicitly, before quoting bands 3 and 4 | The band that constrains the author. See below |

> ## BANDS ADDED 2026-08-22, BEFORE THE CYLINDER IS ORDERED. THE EIGHT ABOVE ARE NOT EDITED.
>
> Added after a sweep of the guided-separation literature, see
> [`EXTERNAL_EVIDENCE.md`](EXTERNAL_EVIDENCE.md). Its usable finding is that a seal force is a
> property of a geometry, a finish and a duty cycle, not a scalar, and four of those properties
> cost nothing extra to record on a rig that is already being built. Nothing above is changed,
> widened or re-thresholded; these are additions, and no data exists for any band on this page.
>
> | # | Question | Band | Why it is worth the extra half hour |
> |---|---|---|---|
> | 9 | Direction dependence, pull each unit both ways | report both, with the spread | The piston travels one way and returns never. A seal with a lip is not symmetric, and if it is, that is a result too |
> | 10 | Conditioning, first pull against the tenth against the last | report the trend over >= 30 pulls per unit | The machine fires twelve times ever. If breakaway falls after the first few pulls, the design point is the *unconditioned* seal and every figure taken from a bedded-in one is optimistic |
> | 11 | The force, time trace, not the peak | commit the trace; report whether stick-slip appears | [A44](../validation/A44_legacy_study_dispersion.md) models friction as a constant allowance. Stick-slip inside a stroke is a different disturbance from a constant offset and would land on dispersion in a way the current model cannot represent |
> | 12 | State the temperature the pulls were made at | report it, and the gap to A58's case | Band 8 enumerates air-side, low-speed and unpressurised, and does not name temperature. [A58](../validation/A58_chamber_thermal.md) puts the gas at 238 K, −35.2 °C every shot. *That omission is recorded here rather than repaired above* |
>
> None of these changes what the order buys. Bands 9-11 are how the same three cylinders are
> pulled; band 12 is a thermometer. If any of them cannot be done, say which and why in the run
> sheet, an undone band is a recorded gap, not a silent one.

> ## BANDS 13 AND 14, DECLARED 2026-08-22, BEFORE PURCHASE AND BEFORE ANY DATA. BANDS 1-12 ARE NOT EDITED.
>
> These two exist because bands 1-8 assumed the load cell measures the seal. It does not, see
> the correction in §1.1. They are prerequisites on bands 3 and 4, in the same way band 8 is:
> *bands 3 and 4 may not be quoted anywhere until 13 and 14 are answered.*
>
> | # | Question | Band | What a miss means |
> |---|---|---|---|
> | 13 | Is the non-target force measured on the same hardware? Pull each unit twice: complete, and again with the piston seal removed and everything else, rod, rod seal, wiper, bearing, alignment, speed, unchanged | both configurations, >= 3 units, >= 10 pulls each; report the difference and its spread | The rig measured a pneumatic cylinder and the run sheet claimed a historical study seal. A tare taken on different hardware, or estimated from a catalogue, does not satisfy this |
> | 14 | Does the result classify? Take the piston-seal friction as the band-13 difference, with its combined 3σ spread. That interval must lie wholly below 17.8352 N, wholly above 22.294 N, or wholly between them | it must not straddle either boundary | P67 is not answered. Band 8's third outcome applies, it is written down as not answered, and the vacuum test is what is needed |
>
> Band 14 declares no new tolerance. Both numbers are [A61](../validation/A61_seal_class.md)'s,
> already in `analysis/results/seal_class.json` as the 4.00 % thermal specification and the 5.00 %
> trim-unnecessary fraction, and they are the two boundaries [ADR-036](adr/036-seal-specification-and-the-trim-stage.md)
> already decides on. The band is a requirement on the measurement's uncertainty, expressed
> against thresholds that were declared before it.
>
> What band 13 still does not remove. The rod remains in the fixture, so any side load it
> imposes acts on the piston seal in both configurations and is not subtracted, it is inside the
> difference. Report the alignment method. And the difference is a *piston seal in a rod
> cylinder*, which is nearer to the machine than the total was and is still not a free piston at
> 22.73 bar and 17 m/s in vacuum. Band 8 governs that, and it always did.

### Band 8 is the one that decides whether the rest is worth anything

An air-side, low-speed, possibly unpressurised bench pull is a *different* measurement from a
16 mm PTFE seal at 22.73 bar and 17 m/s in vacuum. It is not a cheaper version of the right
measurement, and this file will not pretend otherwise.

What it can still do: if the measured running friction is, say, 8 N, then the design point
sits comfortably under 17.8 N *unless* speed and vacuum together more than double it, and the
result discriminates. If it comes back at 19 N, it lands between the thresholds and
discriminates nothing, because the corrections could push it either way.

So band 8 requires the answer to be written down before bands 3 and 4 are quoted anywhere.
The honest outcomes are:

1. Well below 17.8 N to the specification is likely met; ADR-036 can be resolved on a stated
   margin, and the margin is stated.
2. Well above 22.3 N to the stator is needed; A66 is written; vacuum and speed corrections
   would only make it worse, so the direction is safe.
3. Anywhere near either threshold to the bench test has not answered P67, it goes on the
   record as not having answered it, and the vacuum test is what is needed. *This is a real
   possible outcome and it is declared in advance so it cannot be argued away afterwards.*

---

## 3. What to do with the result

Write it as `validation/B2_seal_friction.md` with these bands copied in unchanged, the raw
pulls committed as CSV, both configurations of band 13, not only the complete one, and the
verdict against each. Then, and only then, resolve ADR-036.

It changes the category of evidence, not its degree. `docs/FIGURE_INDEX.md`'s `measured`
evidence class has zero members, and it has been the honest description of this project since
it started. B-1 or B-2, whichever lands first, ends that, and the day it does,
[`E4`](../OPEN_PROBLEMS.md) stops being true and every page that says *"nothing has been built,
fired or measured"* has to be corrected in the same commit.

> Do not let that correction be a celebration. One measured component is one measured
> component. The machine remains unbuilt, and the sentence that replaces E4 should say so.

---

## Provenance

Thresholds from [ADR-036](adr/036-seal-specification-and-the-trim-stage.md) and
`analysis/results/seal_class.json`, 17.8352 N at the thermal specification and 22.294 N at
the trim-unnecessary fraction, both at the 15.805 mm bore and 22.7258 bar charge. Bore
substitution from [A61](../validation/A61_seal_class.md) band 7. Dispersion share from
[A44](../validation/A44_legacy_study_dispersion.md). Piston speeds derived from
`LEGACY_STUDY_drive.exit_velocity_m_s_zero_friction` and `stroke_mm`.

Every price in section 1 is an estimate and no supplier has quoted any of it.

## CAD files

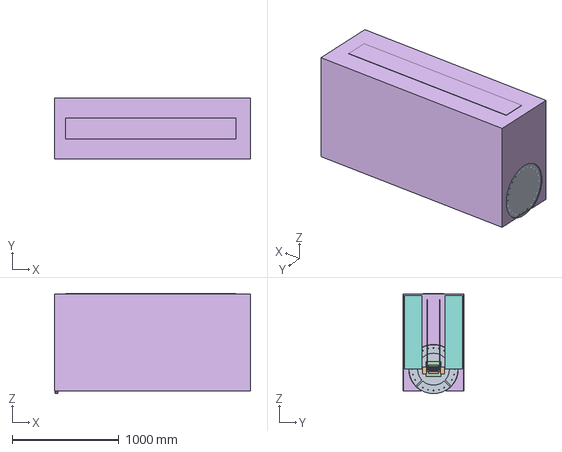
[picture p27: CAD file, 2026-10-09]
cad/step/feeder_candidate_r1/VOLLEY_Feeder_Assembly_FreeCAD_R1.step
1839.0 x 570.0 x 938.3 mm

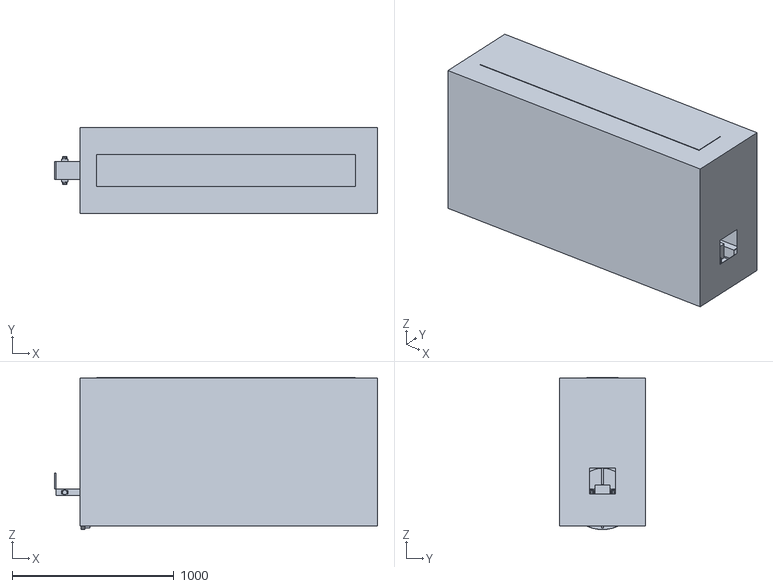
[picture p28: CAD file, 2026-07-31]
cad/stl/EMOCD_Assembly_Gen3.stl
1995.0 x 530.0 x 940.0

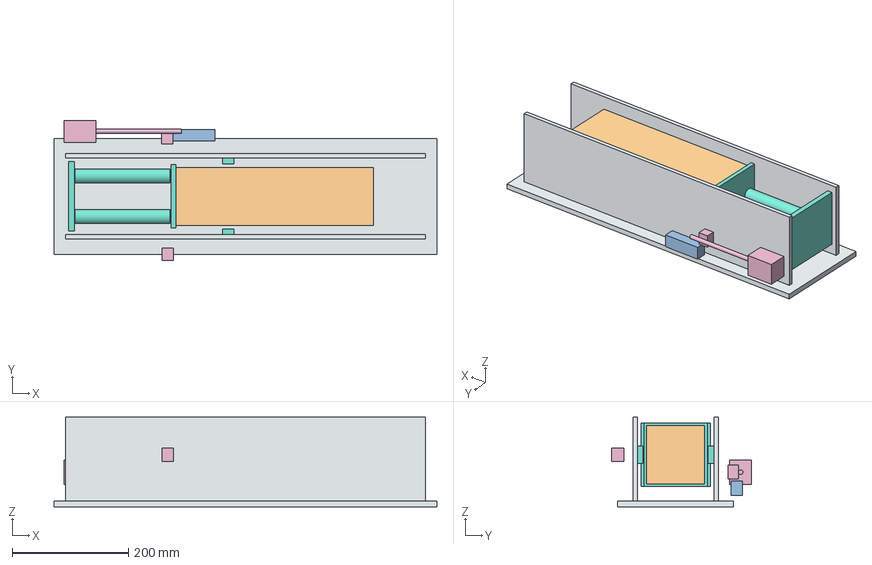
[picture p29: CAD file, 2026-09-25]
cad/lunar_concept/mechanical_cell.step
660.0 x 242.0 x 155.0 mm
cell_mounting_deck
cell_frame_-70
cell_guide_-70
cell_frame_70
cell_guide_70
cell_rear_spring_seat
cell_pusher_charged
cell_payload_proxy
cell_spring_envelope_-35
cell_spring_envelope_35
cell_charger_motor_envelope
cell_charger_screw_envelope
cell_withdrawn_coupling
cell_latch_envelope
cell_catcher_envelope_-62
cell_catcher_envelope_62
cell_sensor_harness_zone

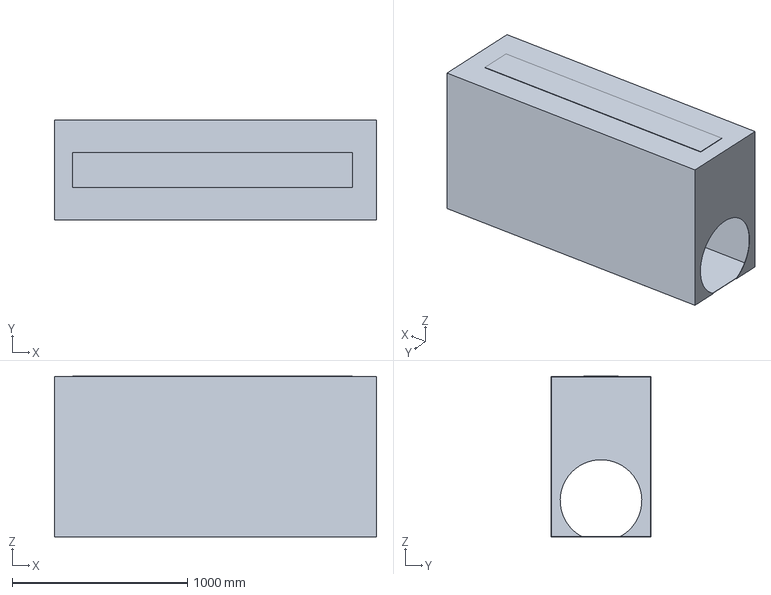
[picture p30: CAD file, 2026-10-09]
cad/step/feeder_candidate_r1/VOLLEY_Wide_Enclosure_R1.step
1839.0 x 570.0 x 917.0 mm

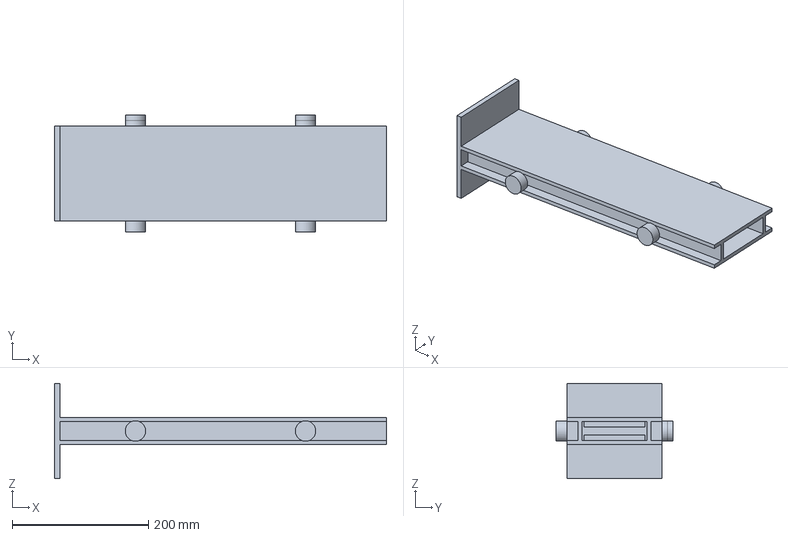
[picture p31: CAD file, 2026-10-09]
cad/step/freecad_gen5/VOLLEY_Sled_FreeCAD_Gen5.step
488.0 x 172.0 x 140.0 mm

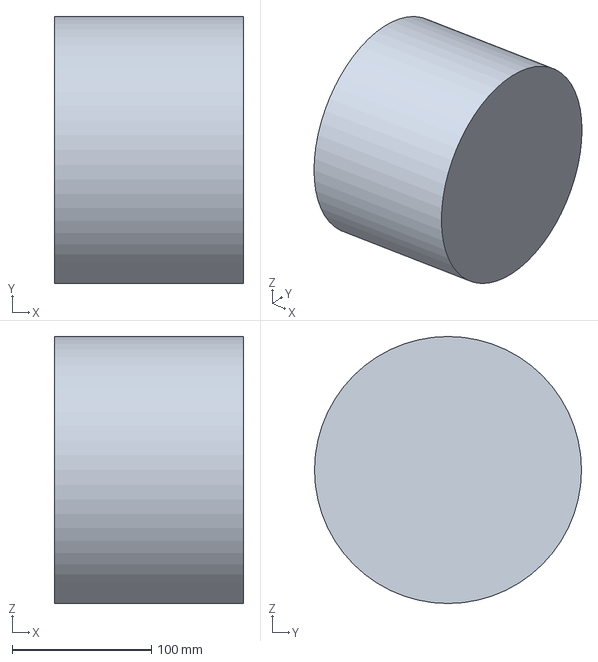
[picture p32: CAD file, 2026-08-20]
cad/step/gen6/VOLLEY_Reservoir_Gen6.step
136.0 x 192.0 x 192.0 mm

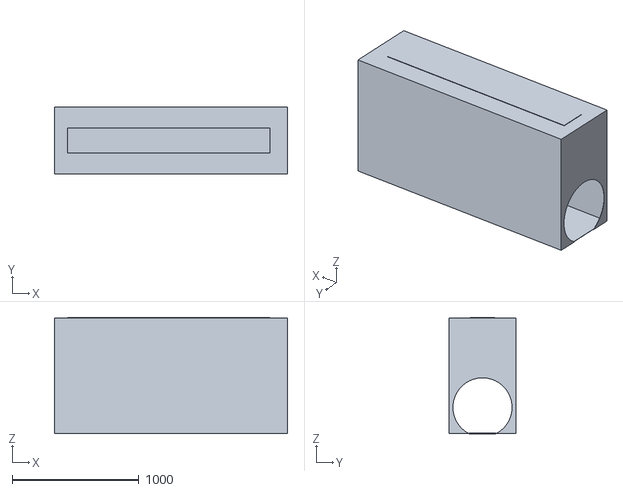
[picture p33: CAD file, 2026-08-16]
cad/stl/gen5_scad/enclosure.stl
1839.0 x 530.0 x 917.0

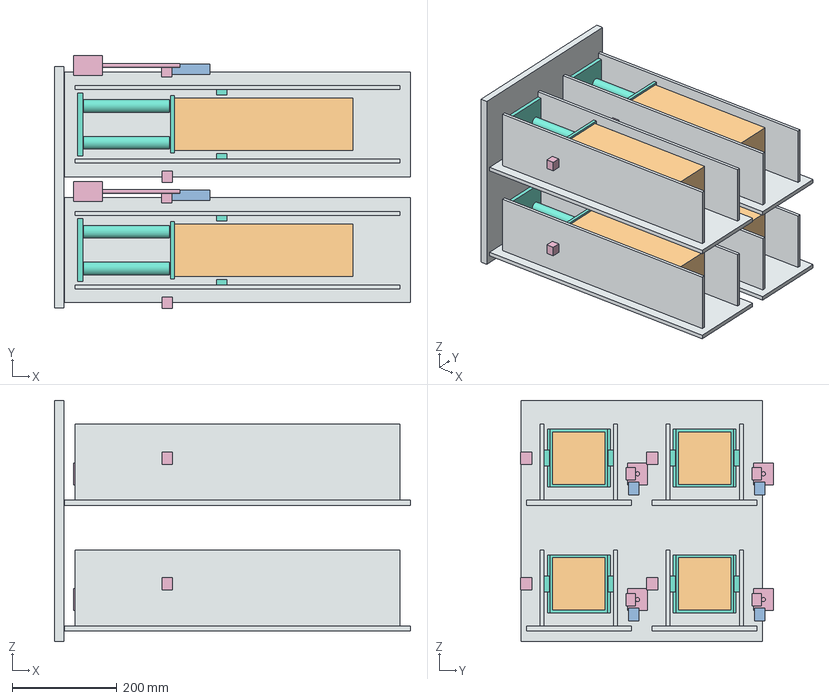
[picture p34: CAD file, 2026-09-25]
cad/lunar_concept/four_cell_bank.step
679.0 x 482.0 x 460.0 mm
cell_0_0_mounting_deck
cell_0_0_frame_-70
cell_0_0_guide_-70
cell_0_0_frame_70
cell_0_0_guide_70
cell_0_0_rear_spring_seat
cell_0_0_pusher_charged
cell_0_0_payload_proxy
cell_0_0_spring_envelope_-35
cell_0_0_spring_envelope_35
cell_0_0_charger_motor_envelope
cell_0_0_charger_screw_envelope
cell_0_0_withdrawn_coupling
cell_0_0_latch_envelope
cell_0_0_catcher_envelope_-62
cell_0_0_catcher_envelope_62
cell_0_0_sensor_harness_zone
cell_0_1_mounting_deck
cell_0_1_frame_-70
cell_0_1_guide_-70
cell_0_1_frame_70
cell_0_1_guide_70
cell_0_1_rear_spring_seat
cell_0_1_pusher_charged
cell_0_1_payload_proxy
cell_0_1_spring_envelope_-35
cell_0_1_spring_envelope_35
cell_0_1_charger_motor_envelope
cell_0_1_charger_screw_envelope
cell_0_1_withdrawn_coupling
cell_0_1_latch_envelope
cell_0_1_catcher_envelope_-62
cell_0_1_catcher_envelope_62
cell_0_1_sensor_harness_zone
cell_1_0_mounting_deck
cell_1_0_frame_-70
cell_1_0_guide_-70
cell_1_0_frame_70
cell_1_0_guide_70
cell_1_0_rear_spring_seat
cell_1_0_pusher_charged
cell_1_0_payload_proxy
cell_1_0_spring_envelope_-35
cell_1_0_spring_envelope_35
cell_1_0_charger_motor_envelope
cell_1_0_charger_screw_envelope
cell_1_0_withdrawn_coupling
cell_1_0_latch_envelope
cell_1_0_catcher_envelope_-62
cell_1_0_catcher_envelope_62
cell_1_0_sensor_harness_zone
cell_1_1_mounting_deck
cell_1_1_frame_-70
cell_1_1_guide_-70
cell_1_1_frame_70
cell_1_1_guide_70
cell_1_1_rear_spring_seat
cell_1_1_pusher_charged
cell_1_1_payload_proxy
cell_1_1_spring_envelope_-35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

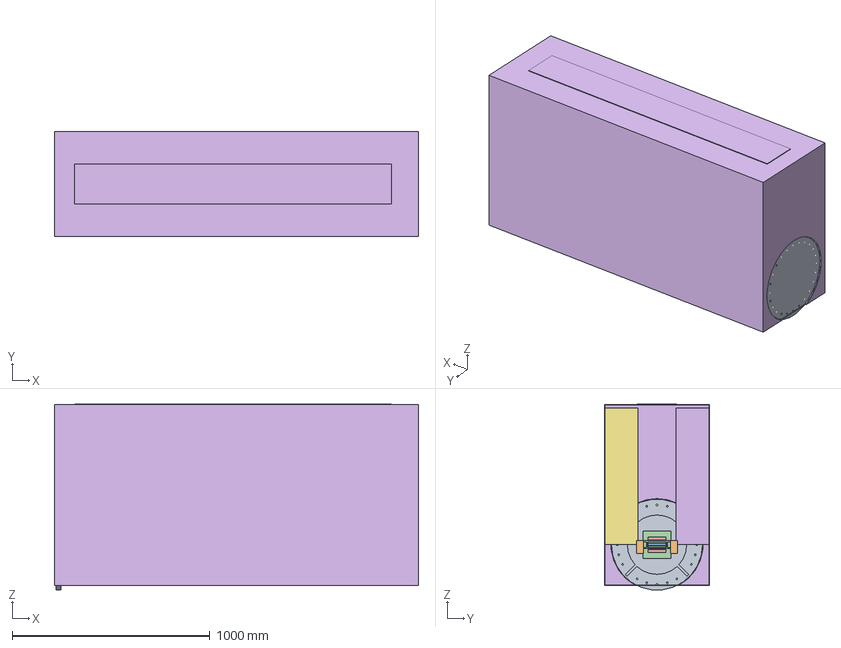
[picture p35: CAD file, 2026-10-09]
cad/native/Gen5_Review.FCStd
1839.0 x 530.0 x 938.3 mm
Interface ESPA
Track
Stator
Sled
Brake
Enclosure
Magazine S
Payload S01
Payload S02
Payload S03
Payload S04
Payload S05
Payload S06
Magazine P
Payload P01
Payload P02
Payload P03
Payload P04
Payload P05
Payload P06

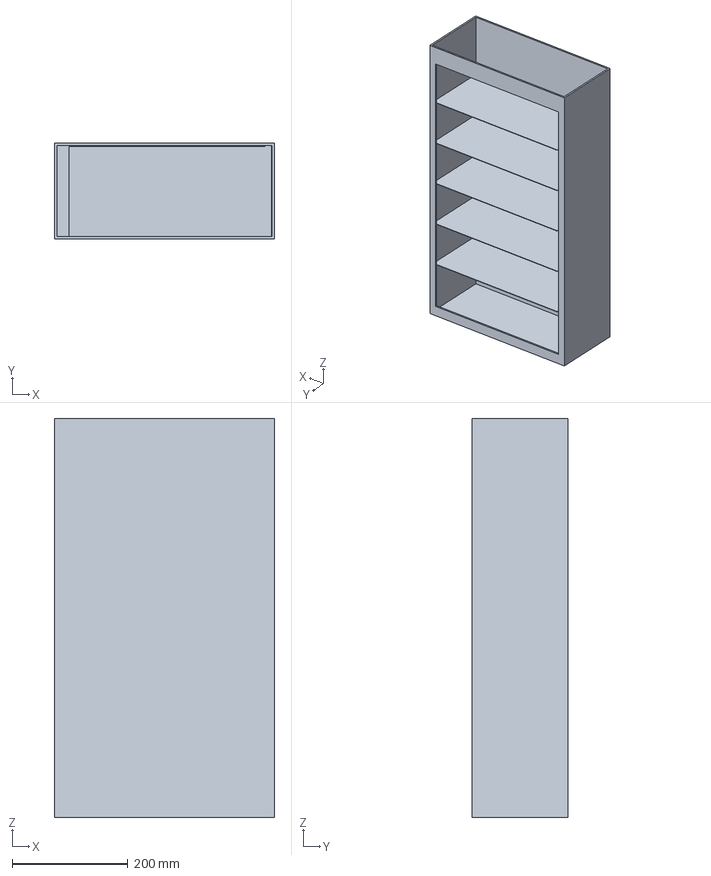
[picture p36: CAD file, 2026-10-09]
cad/step/feeder_candidate_r1/VOLLEY_Open_Cassette_S_R1.step
380.5 x 166.0 x 690.0 mm

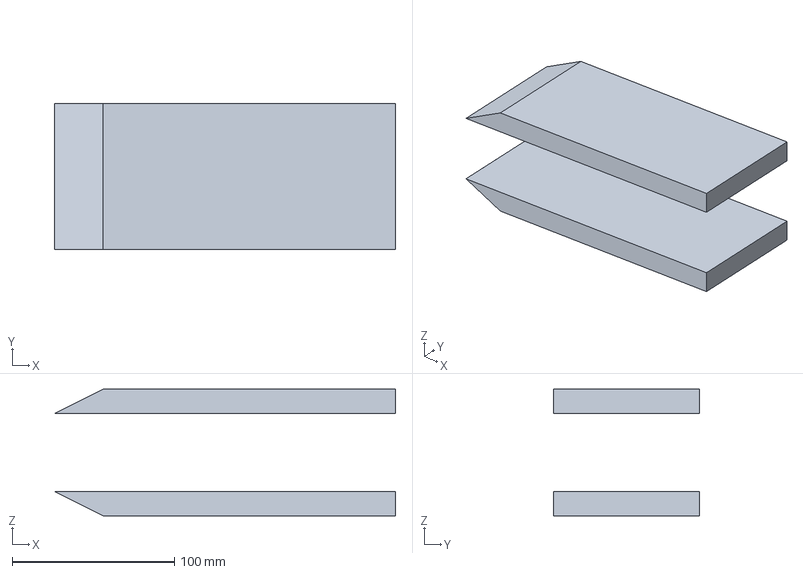
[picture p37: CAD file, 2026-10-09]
cad/step/freecad_gen5/VOLLEY_Brake_FreeCAD_Gen5.step
210.0 x 90.0 x 78.0 mm

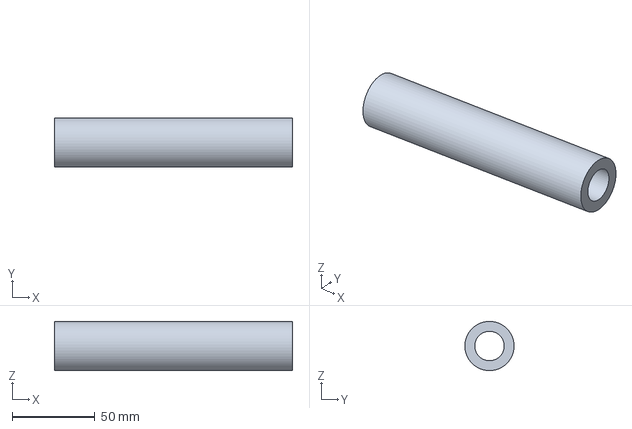
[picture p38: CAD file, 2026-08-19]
cad/step/gen6/VOLLEY_Trim_Stator_Gen6.step
144.0 x 29.8 x 29.8 mm

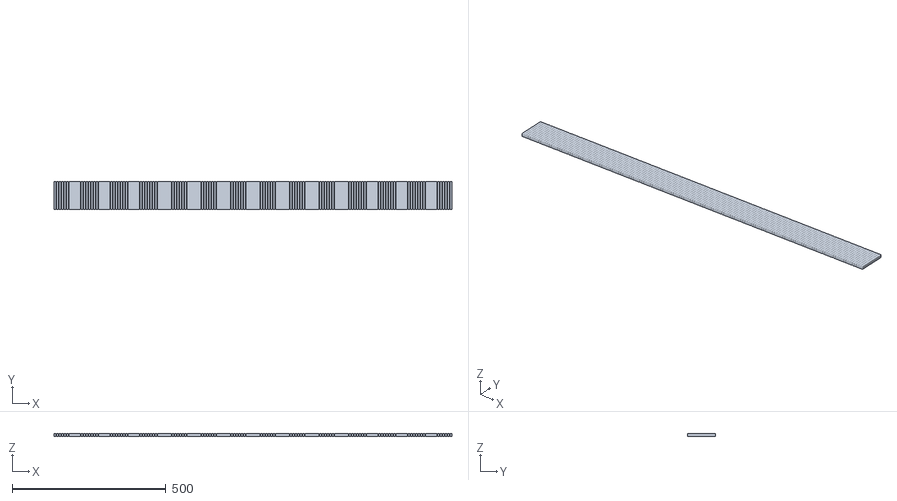
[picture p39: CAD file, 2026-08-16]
cad/stl/gen5_scad/stator.stl
1295.0 x 90.0 x 10.0

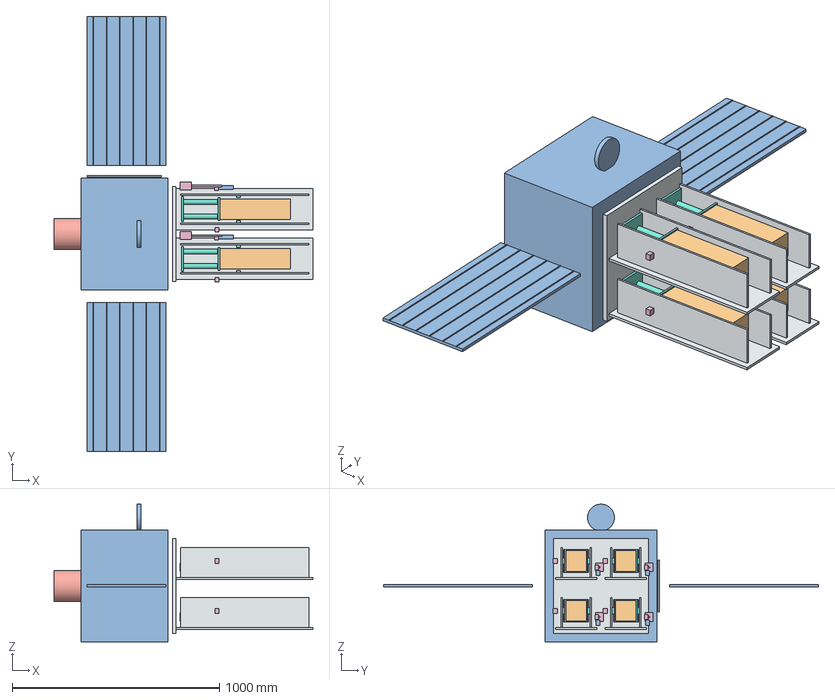
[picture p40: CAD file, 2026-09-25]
cad/lunar_concept/lunar_carrier.step
1250.0 x 2100.0 x 665.0 mm
cell_0_0_mounting_deck
cell_0_0_frame_-70
cell_0_0_guide_-70
cell_0_0_frame_70
cell_0_0_guide_70
cell_0_0_rear_spring_seat
cell_0_0_pusher_charged
cell_0_0_payload_proxy
cell_0_0_spring_envelope_-35
cell_0_0_spring_envelope_35
cell_0_0_charger_motor_envelope
cell_0_0_charger_screw_envelope
cell_0_0_withdrawn_coupling
cell_0_0_latch_envelope
cell_0_0_catcher_envelope_-62
cell_0_0_catcher_envelope_62
cell_0_0_sensor_harness_zone
cell_0_1_mounting_deck
cell_0_1_frame_-70
cell_0_1_guide_-70
cell_0_1_frame_70
cell_0_1_guide_70
cell_0_1_rear_spring_seat
cell_0_1_pusher_charged
cell_0_1_payload_proxy
cell_0_1_spring_envelope_-35
cell_0_1_spring_envelope_35
cell_0_1_charger_motor_envelope
cell_0_1_charger_screw_envelope
cell_0_1_withdrawn_coupling
cell_0_1_latch_envelope
cell_0_1_catcher_envelope_-62
cell_0_1_catcher_envelope_62
cell_0_1_sensor_harness_zone
cell_1_0_mounting_deck
cell_1_0_frame_-70
cell_1_0_guide_-70
cell_1_0_frame_70
cell_1_0_guide_70
cell_1_0_rear_spring_seat
cell_1_0_pusher_charged
cell_1_0_payload_proxy
cell_1_0_spring_envelope_-35
cell_1_0_spring_envelope_35
cell_1_0_charger_motor_envelope
cell_1_0_charger_screw_envelope
cell_1_0_withdrawn_coupling
cell_1_0_latch_envelope
cell_1_0_catcher_envelope_-62
cell_1_0_catcher_envelope_62
cell_1_0_sensor_harness_zone
cell_1_1_mounting_deck
cell_1_1_frame_-70
cell_1_1_guide_-70
cell_1_1_frame_70
cell_1_1_guide_70
cell_1_1_rear_spring_seat
cell_1_1_pusher_charged
cell_1_1_payload_proxy
cell_1_1_spring_envelope_-35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

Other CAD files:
cad/step/feeder_candidate_r1/VOLLEY_Feeder_Assembly_R1.step
analysis/femm/emocd_cross_section.dxf
cad/native/Feeder_Candidate_R1.FCStd
cad/stl/VOLLEY_Reservoir_HistoricalStudy.stl
cad/scad/parameters.scad
cad/scad/gen5.scad
cad/lunar_concept/four_cell_bank.stl
cad/lunar_concept/large_payload_pallet.step
cad/lunar_concept/large_payload_pallet.stl
cad/lunar_concept/lunar_carrier.stl
cad/lunar_concept/mechanical_cell.stl
cad/step/feeder_candidate_r1/VOLLEY_Lift_Guides_R1.step
cad/step/feeder_candidate_r1/VOLLEY_Open_Cassette_P_R1.step
cad/step/freecad_gen5/VOLLEY_Enclosure_FreeCAD_Gen5.step
cad/step/freecad_gen5/VOLLEY_Interface_ESPA_FreeCAD_Gen5.step
cad/step/freecad_gen5/VOLLEY_Magazine_Cassette_FreeCAD_Gen5.step
cad/step/freecad_gen5/VOLLEY_Payload_3U_FreeCAD_Gen5.step
cad/step/freecad_gen5/VOLLEY_Stator_FreeCAD_Gen5.step
cad/step/freecad_gen5/VOLLEY_Track_FreeCAD_Gen5.step
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

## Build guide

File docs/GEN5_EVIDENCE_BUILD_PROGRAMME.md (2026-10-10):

# Gen5 evidence-build programme

**Programme status: in work.** [Issue #44](https://github.com/aaaaaaaaaaaavm/VOLLEY/issues/44) tracks the six scoring gaps. This page defines the engineering routes and the evidence required to close each one. Gen5 is the **evaluated academic configuration**, with adverse results preserved. R1 and every new topology remain **unselected candidate revisions** until their dependent analyses are rerun. Gen6 is the separate future scaling programme; 1 km/s is an objective, not a Gen5 or Gen6 demonstrated result.

## First decision: is this architecture worth carrying forward?

[P123](../validation/P123_gen5_one_event_mass_screen.md) reproduces the fixed-fuel matched reference and re-solves a hypothetical one-event fuel load. At the optimistic finite-force 12.448 m/s conversion, the 126.562 kg Gen5 device is 54.562 kg heavier than a 72 kg spring class. It saves 1.866 kg of fuel for one event with both options loaded with 10 kg. Resizing fuel for only that event still gives a **+52.717 kg device-plus-fuel penalty**. Parity would require about **73.932 kg device mass**, a 52.630 kg reduction, at the same ideal speed. This is a *screen*, not a full-campaign or provider comparison. The existing six sampled twelve-release campaigns do not close.

The first architecture review should ask whether any credible mass and interface revision can approach that threshold **without** losing validated separation speed, structural margin, thermal control, payload protection or reliability. If it cannot, a rigorous IEEE contribution may be the quantified feasibility limit and failed criteria. That is a legitimate study result; it is not a product qualification.

The [necessary one-event bound](../analysis/results/gen5_architecture_bounds.json) shows that even zero host fuel burn would allow only 74.659 kg of Gen5 device for parity in this reference. The unselected [H1 captive passive-armature hypothesis](GEN5_H1_INTEGRATED_DEPLOYER_HYPOTHESIS.md) combines moving-mass reduction with structural integration as a falsifiable candidate. Its component ideas have prior art; neither its mass nor its novelty has been demonstrated.

## 1. Drive, force and power

**Ideas to test:** compare a segmented ironless stator with local commutation, a shorter active winding, different coil pitch and copper fill, and a lower speed command where the mission actually benefits. P120's 0.34 m and 1.30 m energized lengths are exploratory branches, not selected windings. Add the actual end turns, series/parallel connections, bus impedance, switching dead time and position-estimation latency before choosing a branch.

**Build and publish:**
- one source-controlled winding table and inverter/source bill of materials with part numbers, hot/cold resistance, inductance, ESR, continuous/pulsed current, voltage and thermal limits;
- FreeCAD/CadQuery coil and magnet geometry, a 3-D meshed magnetostatic position sweep (open-source candidate: Gmsh plus Elmer or GetDP), and an independent comparison with P121's surface-charge integral and P119's 2-D PDE;
- a circuit netlist (ngspice), explicit switching logic, position-dependent back EMF and force, and coupled electrical/kinematic integration using the same CAD revision;
- voltage/current/force/speed/temperature/energy histories, a closed energy ledger, time-step and mesh convergence, parameter corners, and failed cases.

[P125](../validation/P125_gen5_voltage_limited_screen.md) adds an ideal quasi-steady three-phase voltage/current screen using unselected historical winding and source values. It bounds sensitivity but does not specify a switch, coil or cell. A single string at the older 116–185 mΩ commercial ESR bound fails before release in that model; ideal two- or three-parallel-string branches complete while increasing cell count and source mass.

**Decision gate:** report the **achievable** release range under component limits and uncertainty. The 12.448 m/s ideal conversion is an upper screen until this gate closes. Preserve 16.029 m/s as a historical contradicted result.

## 2. Mechanism, packaging and mass

**Ideas to test:** center lift (R1), a translating shuttle, and a more compact low-count magazine. Score them on restraint during launch, single-payload indexing, fault isolation, reset after an abort, actuator count, service access, moving clearance, width, and installed mass. A lower-count magazine may reduce mass but must be compared on delivered payload count and operations, not per-shot performance alone.

**Build and publish:** one controlled native CAD model per candidate; part and assembly STEP exports; dimensioned envelope/interface/section drawings; identified datum scheme and GD&T assumptions; state-by-state kinematics, swept-solid interference and tolerance stack; hardware/fastener/harness/radiator keep-outs; revised part-level mass, center of gravity and inertia, with material densities and mass margins. Keep a compact design-selection table rather than quietly replacing Gen5 with R1. The current Gen5 side feed has an **11 mm width shortfall**; R1's scripted clearances do not show feed actuation or launch restraint. [P126](../cad/FEEDER_R1_TOLERANCE_SCREEN.md) further shows that R1's 5 mm nominal corridor fails an illustrative 0.5° alignment stack by 0.47 mm, while a 0.2° stack leaves 1.31 mm. These are declared study bands, not released drawing tolerances.

**Decision gate:** a candidate must close its own envelope, swept clearance, tolerance and mass ledger against a *named or explicitly surrogate* payload and host interface. Recalculate the drive and structural modes after any track, enclosure or cassette change.

## 3. Release, brake, safety and payload behavior

**Ideas to test:** use a latched sled with a documented preload/contact law; vary contact stiffness, friction, rail misalignment and trigger skew; include a redundant independent release path only if its added mass and common-mode risks improve the system trade. Compare passive eddy arrest with a hybrid mechanical backup sized for worst-case energy and thermal soak.

**Build and publish:** contact force and tip-off time histories; host reaction impulses/torques; brake deceleration and repeated-shot temperature; reset and jam-clearance envelopes; abort state machine and FMEA; magnetic-field map at payload equipment locations; structural modal/transient response on the *revised* geometry. Use the named payload's acceleration, shock, magnetic and cleanliness limits. Without them, label results as sensitivity cases, not compliance.

[P127](../validation/P127_gen5_release_arrest_bounds.md) now gives necessary ideal-speed sled energy, mean brake load and first-order host momentum bounds using the provisional 210 mm corridor. It does not solve eddy-current peak force, contact or heat.

**Decision gate:** every claimed limit traces to a source or declared study band, with uncertainty and fault corners. Physical bench/qualification tests and provider sign-off remain future work.

## 4. Matched mission, utility and economics

**Ideas to test:** give VOLLEY a mission target it can plausibly help, rather than choosing a spacing target that its higher release speed makes harder. Vary deployment altitude, target phasing time, orbital plane opportunity and release-speed command as a constrained trade. Compare springs plus competent host burns, onboard propulsion, differential drag where deadlines permit, and relevant transport services on *identical* payloads, epoch, host, constraints and accounting boundary.

**Build and publish:** a named reference payload and host or openly labeled surrogate; interface assumptions; twelve-shot sequential propagation and optimization with multiple starts; fuel, battery energy, mass, launch volume, delivery count, covariance/disposal and operations table; sensitivity and feasibility maps rather than a single favorable orbit point. Include failed optimizations as “no trajectory found under these starts and bounds,” not impossibility proofs. P123 is the reproducible one-event baseline for this package, not its conclusion.

**Decision gate:** at least one defined mission must close all twelve releases with the selected drive and installed mass, or the paper states that the studied Gen5 mission does not close.

**P124 update:** the [ideal precision-delivery design-space screen](../validation/P124_precision_delivery_design_space.md) now maps specified 450 km semimajor-axis targets and tolerance bands to tangential velocity requirements and minimum stroke acceleration. It exposes why 1 km/s cannot be assigned to a first ordinary-3U Gen6 article on the Gen5 stroke. It does not close host-state, release-vector or delivery-accuracy budgets. The [Gen6 prototype-to-flight roadmap](GEN6_PROTOTYPE_TO_FLIGHT_ROADMAP.md) makes the subsequent evidence gates explicit.

## 5. IEEE research claim and reproducibility

**Candidate contribution:** a source-graded, falsifiable *system-level feasibility evaluation* of a specific electromagnetic multi-satellite deployment architecture, including an independent force check, coupled constraints, installed burden and adverse mission results. Adjustable electromagnetic separation and stacked feed are prior art; neither is claimed as VOLLEY's invention without a narrower demonstrated distinction.

**Build and publish:** full-text and patent comparison with traceable claim/source/revision, a quantitative comparator table, design/solver convergence, model-form uncertainty, validated code and input/output snapshot, plus an independent technical read with logged responses. Keep analytic agreement, numerical convergence, literature analogy, measured validation and flight qualification as distinct evidence classes. Choose an IEEE venue before declaring compliance with its template or length rules.

**Decision gate:** every abstract number and graph points to one configuration, result file and uncertainty statement. A negative design finding is publishable if the method and scope are tight.

## 6. College release and public package

**Build and publish:** the college-format report, 15-minute two-presenter deck, demonstration route, claim-to-evidence table, figure and drawing indexes, reproducible source/results/CAD/STEP bundle, frozen configuration hashes, known exceptions and an independent panel-style read. Keep individual contribution claims unstated, as requested. Put the adverse 11 mm geometry, installed-mass and twelve-shot findings in the results and viva route, not only in footnotes.

**Decision gate:** freeze one academic Gen5 snapshot only after all figures and PDFs are generated from the same source/result/CAD revision, the repository checks pass on that commit, and all unresolved criteria are explicit. Freeze means a controlled **computational study**, not a built or certified dispenser.

## Publication sequence

1. **Published:** P123 source, committed numerical snapshot, figure and validation record; CI check recomputes the snapshot. This addresses a slice of package 4 and quantifies the package 2 mass target.
2. **Next:** choose one actual drive circuit and one mechanism candidate under an explicitly surrogate payload/host; publish their input sheets and negative as well as passing results.
3. **Then:** run the matched twelve-shot and payload safety analyses on that *same* revision; only then regenerate manuscript claims and presentation visuals.
4. **Final:** obtain an independent technical review and the college's official format; release the evidence bundle with hashes and exceptions. Provider acceptance, physical tests and peer-review acceptance cannot be generated computationally.

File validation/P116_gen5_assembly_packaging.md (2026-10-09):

# P116 — Gen5 reference assembly and packaging screen

**Run:** 9 October 2026. **Disposition:** a named 20-instance review STEP is released, and its stated side-fed reference arrangement **fails** geometric interference. It is not a flight assembly, motion study or an approved interface.

The [assembly generator](../cad/build_review_assembly.py) imports the eight Gen5 STEP parts, places the interface, track, stator, sled, brake and enclosure, adds two magazine cassettes and twelve 3U payload proxies, and exports a named [assembly STEP](../cad/step/gen5/VOLLEY_Review_Assembly_Gen5.step). The [machine-readable report](../cad/REVIEW_ASSEMBLY.json) pins input hashes, placements and exact-solid overlap. A repeat export gave the same SHA-256 after the STEP header was normalized. The [cross-section](../figures/gen5_packaging_section.svg) draws the declared layout, not a manufacturing drawing.

FreeCAD 1.0 also imports the eight solids into a [native FCStd document](../cad/native/Gen5_Review.FCStd), re-exports [eight part STEP files](../cad/step/freecad_gen5/) and a [20-instance assembly STEP](../cad/step/gen5/VOLLEY_Review_Assembly_FreeCAD_Gen5.step), and reads the export back as a valid B-rep. Its independent exact-solid intersection gives the same 32,915 mm³ on each side; software version, hashes and limits are in the [FreeCAD export JSON](../cad/FREECAD_EXPORT.json) and the [CAD review PDF](../cad/GEN5_CAD_REVIEW.pdf). The imported parts are editable in placement and grouping but have no native FreeCAD parametric feature history.

For this side-fed reference, each 166 mm-wide cassette is placed against the internal side face of the 530 mm-wide, 2 mm-skin enclosure. Internal clear width is **526 mm**. Two cassettes plus the 205 mm-wide track need **537 mm before any clearance**, an **11 mm shortfall**. At the declared 200 mm cassette x offset and z=0..690 mm, exact B-rep intersections find **32,915 mm³ track/cassette overlap on each side**. The cassettes also have zero side-wall clearance. The reference placement therefore does not pass fit. A different vertical feed, cutout or larger enclosure could alter the outcome, but none is modeled or cleared here.

This assembly does not resolve feeder motion, retention, stator end turns, wiring, fasteners, tolerance stacks, thermal growth, structural load paths or an actual CubeSat/host ICD. STEP proxy volumes must not be turned into the 126.6 kg model rollup: materials, fill, components and several masses use different assumptions. The current 3U design should be described as an evaluated computational configuration **with a packaging defect**, not a completed manufacturable product.

Reproduce with `python3 cad/build_review_assembly.py` after `cad/build_gen5.py`; the part hashes in the report allow a reviewer to establish which solids were assembled. Run `python3 cad/plot_review_packaging.py` to rebuild the section figure.

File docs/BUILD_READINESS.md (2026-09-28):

# Build readiness

Updated 2026-09-14. I have not released either VOLLEY configuration for full-system manufacture.
No hardware has been built, fired, measured, qualified or flown.

This page replaces a stale subsystem snapshot which mixed early Gen5 and historical study results with
later corrections. The [previous text](https://github.com/aaaaaaaaaaaavm/VOLLEY/blob/67939b7cbef9e2414226f683ebc12f2b6bf01088/docs/BUILD_READINESS.md)
remains available as history. Current result authority belongs to the run sheets and controlled
inputs, not to that snapshot.

## What a builder can use now

| Material | Use | Boundary |
|---|---|---|
| [Gen5 baseline](BASELINE.md) and [closure](GEN5_CLOSURE.md) | Reproduce the electromagnetic comparison case and inspect its failed criteria | Frozen analysis with exceptions, not a flight design |
| [Parametric CAD](../cad/README.md) | Inspect the modelled geometry and rebuild documented scopes | Nominal fit does not establish tolerance, joint, material or assembly readiness |
| [historical study Fusion handoff](LEGACY_STUDY_FUSION_BUILD_PACKAGE.md) | Follow the assembly tree, datums and parameter ownership | Open geometry and contact questions remain explicit |
| [Manufacturing study](MANUFACTURING.md) | Starting tolerance, process and make/buy reasoning | Must be reconciled to the selected prototype configuration |
| [Benchtop tests](BENCHTOP_TESTS.md), [B-1](B1_ORDER.md), [B-2](B2_ORDER.md) | Starting experiment designs and instrumentation questions | Procurement, facility checks, calibration and execution are not established |
| [Qualification plan](QUALIFICATION_PLAN.md) | Structure an environmental verification campaign | Mission-specific applicability and physical tests remain necessary |

## Current subsystem disposition

| Scope | Existing evidence | What prevents a complete build release |
|---|---|---|
| Gen5 electromagnetic drive | Frozen operating point, field studies and circuit checks | Purchasable pulse chain, model limitations and measured force/compatibility |
| Gen5 structure and retention | Sled and retention-pin calculations; nominal geometry | Remaining track dynamics, interfaces and measured structural response |
| Gen5 brake and recovery | ADR-030 operating point and explicit remaining questions | Brake field/thermal/packaging and physical arrest evidence must be reviewed for the actual article |
| Gen5 host interaction | A52 addresses the missing angular-impulse calculation | Host-specific mass properties, control authority and interface loads |
| historical study gas store and campaign | Precharge, fill, thermal and reservoir-sizing studies | Selected hardware, complete package and campaign uncertainty; computed sizing is not pressure-system qualification |
| historical study guide, piston and cradle | Parametric geometry and the A67–A71 contact investigation | P103/P108: credible contact/exit-state prediction, tolerances, compliant/load-bearing details and actual assembly |
| historical study trim | A72–A74 expose conducting-wall and secondary problems | P92 architecture decision; the trim stage remains suspended |
| historical study release and retention | Requirements and preliminary mechanism/fault work | Complete load path, ascent inhibits, release logic and measured tip-off |
| Both systems' installed budgets | Existing mass, energy and uncertainty studies | Every required purchased and manufactured part tied to the selected configuration; allowances remain labelled |
| Both systems' payload/host interfaces | Public reference cases and parametric requirements | Actual provider/bus data and review; unmodified does not mean universally compatible |

These are engineering-review dispositions. They do not change a run's pass/fail result or close
an entry in [OPEN_PROBLEMS.md](../OPEN_PROBLEMS.md).

## The next useful release

I am targeting a **prototype design-review package for a named configuration**. Its content and
dependency order are in [PROTOTYPE_READINESS.md](PROTOTYPE_READINESS.md). The first article should
be selected to discriminate the controlling uncertain models, rather than to look like the whole
flight machine before those models are trustworthy.

A complete package needs controlled drawings and BOM, material and purchased-part sources,
tolerance/load-path analysis, assembly and inspection instructions, instrumentation and an
uncertainty budget, predicted observables, and a test procedure with acceptance and stop criteria.
It must also identify which test data may calibrate a model and which remain independent checks.

## Work already identified

Use [STATE_OF_THE_PROJECT.md](STATE_OF_THE_PROJECT.md) for the active configuration,
[BSX_REVIEW.md](BSX_REVIEW.md) for the generated live-item list, and
[COMPUTATIONAL_CLOSURE.md](COMPUTATIONAL_CLOSURE.md) for the analytical closure gate.
Programme-scoped P113 still controls the release-velocity requirement even though the legacy_study-only
closure count excludes it. A numerical backlog count is not a build-release decision.

Model credibility, manufacturing readiness, test readiness and flight readiness are separate
claims. I require evidence for each rather than letting a completed CAD assembly stand in for all four.

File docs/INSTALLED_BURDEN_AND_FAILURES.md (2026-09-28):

# Installed burden and failure consequences

> **Architecture disposition, 2026-09-28:** The separate motor-charged spring-cell bank is withdrawn as VOLLEY's next architecture. It is retained here only as a dated study. Any selection or current-reference wording below describes the former decision and is superseded. A reusable shared launch path with sequential loading is the open design objective; no speed envelope is validated. See [current status](NEXT_GENERATION_STATUS.md).

This page retains accounting and fault topology from the earlier [architecture trade](https://github.com/aaaaaaaaaaaavm/VOLLEY/tree/548ad101b2d3f9605079274837081be4a407c11c), associated with closed PR36. The later [independent-cell screen](LEGACY_STUDY_REFERENCE_ARCHITECTURE.md) is also withdrawn as the selected reference. The counts below are conditional topology outcomes, not reliability probabilities or a complete-system selection.

## Twelve-payload topology, with no invented reliability

| Arrangement | Payloads potentially deliverable after one blocked path | Stranded by that path | Shared command/power failure |
|---|---:|---:|---|
| Independent cells | 11 | 1 | Can stop all 12 unless common services are separated |
| Banks of 2 | 10 | 2 | Same common-service obligation |
| Banks of 3 | 9 | 3 | Same common-service obligation |
| Banks of 4 | 8 | 4 | Same common-service obligation |
| Banks of 6 | 6 | 6 | Same common-service obligation |
| One shared magazine/path | 0 | 12 | Can stop the whole manifest |

These are consequence counts, not probabilities, reliability estimates or guaranteed delivered payloads. A jam must be physically isolated from neighbouring cells for the first row to apply. Contamination, structural damage, harness damage and software common causes can violate that assumption.

## What the installed ledger must contain

| Burden | Conventional spring/timing baseline | Independent programmable cells | Shared-path machine | BOLLEY Fluxrelay |
|---|---|---|---|---|
| Payload-side hardware | Selected compatible dispenser interface | Unmodified-payload objective still unverified | Configuration-specific interface | 0.37136 kg modelled increment per spacecraft |
| Release mechanism | Spring and retention package unselected | Spring/store, charge drive, latch, pusher and catcher unselected | Guide, handling, actuator and arrest package | 15.908 kg primary material; partial subtotal |
| Power electronics | Release electronics unallocated | Motor drive, inhibit and monitoring unallocated | Configuration-specific power chain | 2.5488 kg selected modules only |
| Structure and launch retention | Must be charged | Per-cell plus common support | Shared support plus manifest restraint | Cage attachment, guide/support and retention open |
| Thermal, harness and controls | Must be charged | Shared service allocation open | Shared service allocation open | Cooling, DC link, protection and wiring open |
| Host resources | Navigation, pointing, burns, clearance and disposal | Same mission duty and reserve accounting | Same mission duty and reserve accounting | Same, with cooperative-payload burden |
| Complete installed mass | UNKNOWN | UNKNOWN | UNKNOWN | UNKNOWN |

For BOLLEY, 15.908 + 2.5488 = **18.4568 kg** is a rounded partial primary/module subtotal, not an installed system. A twelve-spacecraft manifest would carry twelve passive interfaces; that is an explicitly different accounting scope from a single reference shot. The interface is not free because it is carried by the customer.

For twelve independent cells, write installed mass as `12 × complete cell mass + common services + host support`. For banks, charge every retained payload interface as well as each bank's complete path and services. A shared path may reduce repeated actuator mass while adding feed, return, jam recovery and common-failure burden. Unknown terms stay unknown.

## What the new mechanical screen adds

[P92-S2](REFERENCE_CELL_MECHANICS.md) narrows force, stroke, stored energy and catcher work. It does not supply component mass. The 48 feasible analytical cases cannot support a mass winner until spring geometry/material, latch/load path, charge mechanism, catcher dynamics and mounting are actually selected and checked.

The fair comparison uses a competent selected spring with release timing and the same host manoeuvre authority. It includes spacecraft-side mass and full-manifest host reserves. The S4 2.777987 kg best-tested fuel result is for its two-payload campaign; it must not be presented as a twelve-payload mission result.

## Reference-cell failure review

| Failure | Consequence to analyse | Evidence needed before acceptance |
|---|---|---|
| Premature release or latch failure | Unsafe departure, neighbouring payload exposure | Independent restraint/inhibit architecture, ascent loads and no-fire tests |
| Charge drift or sensor error | Wrong release energy | Calibrated force/travel measurement, dwell/thermal/cycle repeatability |
| Pusher skew, friction or contact loss | Velocity error, tip-off, jam | Six-degree-of-freedom model, tolerance stack and instrumented stroke |
| Catcher rebound or fracture | Recontact, debris, host impulse | Dynamic arrest model and measured peak/rebound envelope |
| Common power/command failure | All cells unavailable | Explicit service segmentation and failure injection |
| Thermal/campaign accumulation | Drift between shots | Full manifest duty, dwell, recovery and host energy balance |

These are unscored failure-review entries. Occurrence probabilities and detectability scores would be invented without a declared implementation and evidence. P92 remains open.

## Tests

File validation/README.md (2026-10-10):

# Validation plan

> **New current finding (P118).** A finite-array/stator 3-D analytic force integral gives 1.042 kJ ideal work and a 12.448 m/s geometry-only speed under ideal phase, challenging the historical 16.029 m/s periodic shot. It shares the earlier cuboid magnetic field law and is not an independent FEM or measurement. See [P118](P118_gen5_finite_force_map.md), the [result JSON](../analysis/results/gen5_finite_force_map.json) and [matched mission screen](../docs/MATCHED_MISSION_REFERENCE.md). The older run-sheet count below describes the historical A-series table, not these new P-series review checks.

> **Independent 2-D follow-up (P119).** A triangular-mesh magnetostatic PDE calculation supports the finite-array end-of-stator force decline and gives 1,081.6 J ideal in-plane work on a 1 mm mesh. The 2-D method omits magnet-depth effects and does not certify the full 3-D force or a coupled shot. See [P119](P119_gen5_finite_force_fem2d.md) and its [solver output](../analysis/results/gen5_finite_force_fem2d.json).

> **Depth-resolved 3-D follow-up (P121–P122).** An independent numerical surface-charge implementation agrees with the ideal finite-cuboid integral at 1,041.7 J; [P121](P121_gen5_finite_force_surface3d.md) records convergence and field probes. [P122](P122_gen5_finite_force_sensitivity.md) varies gap, depth offset, remanence and moving mass as deterministic scenarios. These are model checks with shared design inputs, not a selected motor, measured tolerances or hardware validation.

> **One-event installed-burden follow-up (P123).** [P123](P123_gen5_one_event_mass_screen.md) re-solves the matched reference after hypothetically resizing fuel for one ideal release. The Gen5 device-plus-one-event-fuel proxy is 52.717 kg above the spring class despite 1.866 kg less fuel consumed with both carrying the original 10 kg load. The [labeled figure](../figures/gen5_one_event_installed_burden.svg) and [stdlib source](../analysis/gen5_one_event_mass_screen.py) show the calculation. This is not a twelve-shot campaign, selected drive, or launch-mass claim.

Independent cross-checks of the claims in `analysis/`. The historical A-series
table below contains 73 rows; newer P-series review checks are linked above. A73 is
declared and executing.

> ### This index was nineteen rows short until 2026-08-30, and said so nowhere
>
> It opened by describing *"nineteen of the twenty-one below"* while the directory held 73 files.
> Fifteen run sheets written between A15 and A34 and every run from A66 onward were absent, so a
> reader taking this page as the index of the validation work would have missed A72's finding
> entirely. Nothing checked the table against the directory; the counts gate checks how many run
> sheets exist and never checked whether they were listed.
>
> The missing rows are added below and the header now states a number that can be recomputed from
> `ls`. The rows for A15 and A28 to A34 were written from those run sheets' own Result headings on
> the day the gap was found, seventeen days after the last of them ran, and they are shorter than
> the rows written at the time.

## Why it exists

This directory was written when `PROVENANCE.md` could point at only two cross-checks, the
Halbach field (analytic vs magpylib) and orbital decay (orbit-averaged vs Cowell RK4), both
internal, and the field one analytic-against-analytic, so not confirmation by a different
physical method (`OPEN_PROBLEMS.md` E2).

That has changed, and not uniformly in the project's favour. A1 put a meshed PDE solve
against K<sub>t</sub> and agreed to 0.03 % after correcting shared quadrature. A4 put CalculiX against the chassis and it passed.
A12 put two independent numerical methods against the array attraction and found the published
value 37 % high. And A5 failed: an independent propagator falsified an invariance claim
that was in the paper's own abstract.

What has still never happened is a measurement. Every row below is one model against
another model (E4). Each analysis closes a specific named item.

| # | Analysis | Tool | Closes | Status |
|---|---|---|---|---|
| A1 | Airgap field, 2-D magnetostatic | scikit-fem + gmsh (FEMM substituted) | E1 (2-D half), E2 (partly) | RUN 2026-07-29, verdict PARTIAL: K<sub>t</sub> agrees to 0.03 % after correcting shared quadrature, two bands missed with causes (P20, P21) |
| A4 | Sled chassis structural | CalculiX ccx 2.21 | P5, P8 | RUN 2026-07-28: as-drawn plate passes all three bands |
| A5 | Orbital lifetime and seeding | GMAT R2022a | E6, hardens x1.80 | RUN, verdict FAIL on invariance. See [`../docs/RESULTS.md`](../docs/RESULTS.md) |
| A9 | Decay rate against flown CubeSats (TLE history) | Space-Track + numpy | E6, against reality rather than another model | NOT RUN, blocked by network policy here and re-tested 2026-07-31. Candidate objects now shortlisted in the sheet, so this is an afternoon elsewhere |
| A6 | Conjunction probability | scipy 2-D Pc (CARA substituted) | P1, not closed | CORRECTED 2026-08-03: fixed-shape claim retracted; current slab bound 4.4e-5, two of five bands, three VOID, P1 open |
| A7 | Separation and tip-off | Project Chrono | E7-adjacent | SUPERSEDED 2026-08-20 by [A23](A23_tipoff_release.md) and [A34](A34_cradle_restitution.md), which answered it, ideal release 0 °/s, skew tolerance 50.6 µs, and the cradle rattle settles in 27.25 ms of a 146.4 ms stroke leaving *exactly zero* residual rate. A7 itself stays correctly unrun. A7-R RUN 2026-08-05 instead: Chrono is unavailable and the release mechanism is undefined, so the tolerance was computed rather than the rate, the full push may act unbalanced for only 50.7 µs before the 2 °/s band breaks |
| A8 | Pulse-power chain | ngspice / PySpice | E17 | RERUN 2026-08-05 as A8-R2 at the corrected point: six of six bands, exit velocity agrees to 0.016 % |
| A10 | Shot against a realistic bank ESR | `motor_model.shot()` | nothing; opened P26 | RERUN 2026-08-03: hard ceiling 68 mohm, five of six bands, one VOID |
| A11 | Regenerative recovery of sled energy | `motor_model.regen_brake()` | nothing; asks what R5 did not | RERUN 2026-08-03: 291.4 J recovered, eight of eight bands. Superseded as a current figure: that run integrated over the 240 mm section [ADR-030](../docs/adr/030-apply-the-depth-resolved-thrust-constant.md) removed. At the 39 mm that survives, recovery is 47.0 J, 3.9 % of the sled's energy (P97) |
| A12 | Inter-array attraction, two numerical methods | magpylib + surface Maxwell stress | P17 | CORRECTED 2026-08-03: extended stress plane 2680.0 N vs 2686.6 N volume force; five of five bands |
| A13 | Indexing and sled-return attitude disturbance | momentum bookkeeping | E24 | CORRECTED 2026-08-03: transient-rate rows 3/4 FAIL, row 7 VOID; ideal residual rate is zero and the cadence conclusion is superseded |
| A14 | EMI scoping: payload coupling and comms | `drive_electrical` + magpylib | advances E12; opened P34 | RUN 2026-08-05, verdict PARTIAL: six of eight bands, band 4 FAIL at 611x, band 5 VOID. The dominant term is the static magnet field, not the drive |
| A16 | Gen4 finite-stator thrust vs sled station | magpylib | E27 | RUN 2026-08-05: full-overlap thrust reproduces `F_cmd` to 0.000 %; Gen4 reaches 13.390 m/s, 81.7 % of Phase I, an upper bound |
| A17 | Ripple chirp through the track modes | scipy SDOF | E23; opened P36 | RUN 2026-08-05, verdict FAIL: 8.18x amplification at the fundamental crossing of the 109 Hz mode, and Q is not the variable that saves it |
| A18 | Brake, magnet eddy, fin transient, launch restraint, standoff | numpy + Miles | E20, E19, E26, E22, and E10's analysis half; opened P37 | RUN 2026-08-06: E19/E26/E22 pass, E20 passes only for a 0.4-0.5 T pole field, E10 FAILS at every Q |
| A20 | Reachable orbit envelope vs host Δv budget | numpy + `astro.py` | nothing; quantifies ADR-024, advances PII-6 | RUN 2026-08-10, verdict band 1 FAIL: the band named a two-burn Hohmann and its limit was computed for one burn. Band 3 caught a sign bug in the script. Host supplies 56 % of the altitude extent at 100 m/s |
| A21 | VOLLEY against springs, drag and cold gas, identical axes | numpy + `astro.py` | nothing; replaces the headline ratio | RUN 2026-08-10: seven of seven. 7.52x the lifetime extension of the fastest spring against 6.56x on velocity; mass parity at 1.062; cold gas wins at 3U by 7.5x, declared as a loss in advance. RE-RUN 2026-08-14 at the corrected operating point (P53): still seven of seven, at 7.33x, 6.41x, parity 1.062 and 8.3x |
| A22 | Retention gate resize against the random-vibration case | numpy + `phase1_closeout.e10` | P37, E10's analysis half | RUN 2026-08-10: six of six. 2 x D6 to 2 x D9 takes the margin at Q = 30 from −0.36 to +0.45 and keeps it positive across Q = 10-30, for 11 g |
| A23 | Tip-off at release, modelled rather than bounded | numpy rigid body | advances E7; opened P41 | RUN 2026-08-10: release is comfortable, it happens 12.2 ms into coast at zero force. The payload arrives in its cradle at 36-231 °/s, 18-115x the band, and nothing had modelled it |
| A24 | The payload ladder as a fixed-cell design, not a volume ratio | numpy + `payload_family.py` | ADR-025; opened P44 | RUN 2026-08-10: five of six, band 6 FAIL. 1U no longer closes kill criterion 1 (36/load, 2.125 kg, not 40/1.913); ThinSat and 12U do not fit at all, the 166 mm cassette width is a constraint written nowhere else. Band 6 missed at 0.508 % against 0.5 %: 720 ChipSats need 7.19 kg of shim hardware for 3.6 kg of payload |
| A25 | A flywheel energy store against P26 | numpy + `motor_model.py` | targets P26; opened P45 | RUN 2026-08-10: five of six, band 4 FAIL by 1.1 kg. Band 6, the point of the exercise, passes decisively: 35 mΩ against A10's 68 mΩ ceiling, 66 kW deliverable against 32.5 required. Needs no architecture change. Mass parity, not saving; the miss turns on one unsourced machine specific-mass figure |
| A2 | The 3-D field, and the depth assumption inside K<sub>t</sub> | numpy + magpylib | closes E1's 3-D half; opened P46 | RUN 2026-08-10: four of four run, band 4 (getdp FEM) NOT RUN so E2 stays open. The field was never 2-D, the *thrust integral* was. Resolving depth costs 4.42 % of K<sub>t</sub> (10.5386 to 10.5386), v_exit 16.029 to 16.029. Baseline not changed; computed and held. Band 1 caught a 57 % normalisation bug in the analysis; band 3 was badly chosen and measures numerical cancellation at 10⁻²⁰ T |
| A27 | Why a linear motor, and not a screw, rack or spring | numpy + `motor_model.py` | answers review item 18 | RUN 2026-08-10: screw disqualified by kinematics (49,164 rpm; DN 8.2x over, critical speed 37x under); rack fails on vacuum contact at 16.0 m/s; a ~1.8 kg spring works at 21.1 g and fails only on commandability. The motor is chosen for commandability, not performance |
| A35 | Every kilogram attributed to the requirement that causes it | `mass_properties.py`, no new physics | nothing; quantifies whether kill criterion 1 is reachable at all | RUN 2026-08-14: seven of seven. Energy arriving during the shot is the largest single driver at 28.1 %; an unmodified satellite costs nothing, which calibrates against the sibling repository's negative result. The lattice saturates at 29.94 %: 88.67 kg survives every deletion in every combination, 7.39 kg per satellite, so no architecture change closes kill criterion 1. *(The run sheet still prints the pre-A46 49.23 kg / 4.10 kg pair, P95.)* The prediction of >40 % for the pulse alone was wrong |
| A36 | Magazine density, the only lever A35 left on kill criterion 1 | numpy-free, `constraint_ledger.py` | opened P59 | RUN 2026-08-14: six of seven, band 4 FAIL. The N to ∞ limit is a healthy 0.954 kg/satellite, but 2.0 kg is first reached at N = 116, which no factorisation packages inside the track length. Largest that fits is N = 126 at 1.941 kg/sat on a 244.6 kg machine, 42-hour campaign. At N = 24 it is 4.330 kg, not the 2.05 estimated from A35 by naive division |
| A37 | The stage as the deployer, and A35's falsification test | numpy-free, `constraint_ledger.py` | advances P59; opened P60 | RUN 2026-08-14: six of eight, bands 4 and 8 FAIL. Of 126.56 kg, 29.75 is deleted by historical study physics, 43.33 is stage structure and 11.45 kg is added, all of it containment. Added mass per satellite is 1.608 kg on a small kick-stage class, so kill criterion 1 closes at 3U, with dry mass per satellite still crossing at 7.044 and both reported together. The store scales as v² and reaches 78.5 % of added mass at 8 m, so the binding constraint moves from mass to energy storage |
| A38 | Does A34's cradle closure survive the historical study operating point? | numpy-free, imports `cradle_restitution.py` | advances kill criterion 4; opened P61 | RUN 2026-08-14: five of six, band 1 FAIL. At 2.4x the offset moment the closure improves, settling 17.69 ms of 133.3 against 27.88 of 150.1, critical restitution 0.9462, residual still exactly zero. Tip-off's ceiling is 30.9 g, above the 25 g cap, so it does not bind and A37's window stands. Cost is preload, 81 to 202 N per contact. Band 1 caught A34's recorded figures being stale by 2.3 % against its own script |
| A39 | The energy store at metre-scale strokes | numpy-free | closed P60; settles A35's falsifier | RUN 2026-08-14: seven of seven. At 32.7 m/s a steel spring is 11.41 kg and busts the budget at 34.3 m/s; cold gas is 2.98 kg and busts it at 89.4, on a 1.71 L bottle for all twelve shots. Not energy density, a spring must be cocked twelve times and gas does not. A35's falsifier passes: 2.98 kg against 14.26. The binding constraint on velocity moves from mass to stroke length |
| A40 | The blowdown transient, and how velocity is commanded | numpy-free | opened P63; amends ADR-032 | RUN 2026-08-14: three of eight, bands 1, 3, 6, 7, 8 FAIL. A fixed orifice cannot hold force over a 2.18 m stroke, 4.7 g mean delivered against 25 needed, 14.16 m/s against a 30 m/s band. Flow area was never the problem (0.71 mm against a 10 mm limit); a fixed area cannot track a growing volume. A39's 2.98 kg assumed a regulator it never named. What survives: one 1.71 L bottle does run twelve shots at 4.5 % droop. Band 1 was a declaration error and is recorded as one |
| A41 | The pre-charged chamber: charge slowly, fire as a closed expansion | numpy-free | closed P63; specifies historical study's store | RUN 2026-08-14: eight of eight. A 2 L chamber at 50 bar gives 30.54 m/s at 25 g on a 4.66 kg store, no regulator, no flow-rate problem. Added mass per satellite 1.343 kg against A37's 1.608, at a higher velocity. Velocity commanded by charge pressure at 0.499 % per 1 % against valve timing at 10.53 % per ms. All three stated predictions were wrong, on a run where every band passed |
| A42 | The fill window, and the gas a bottle cannot give back | numpy-free | opened P64; answers ADR-032's falsifier | RUN 2026-08-14: five of six, band 3 FAIL. Filling is 4.14 s through a 1 mm orifice and is not the constraint. A41's 6 L bottle runs out at shot seven of twelve, below the charge pressure it cannot fill a 50 bar chamber. Correction is bounded: 7.65 L isothermal, 11.25 L adiabatic, added mass per satellite 1.344-1.455 kg. The first prediction written before its run that held |
| A15 | A twelve-satellite campaign from POEM, propagated in GMAT | GMAT 2022a | P31, and it falsified an invariance claim in the paper's own abstract | RUN 2026-08-06, three cases. Band 4's prediction was wrong by 28x and band 6's coarse number by 5.7x, both corrected in place with the wrong values kept. R3 reaches 0.7315 deg against a 0.75 deg limit. P16's lifetime invariance is withdrawn and the ratio is quoted at a stated activity level |
| A21-R | Historical timing-only phasing comparator | numpy-free | withdrawn; see P113-S16 | **WITHDRAWN 2026-10-09:** the six historical band verdicts rested on confusing absolute host motion with relative payload phase. Zero-impulse waiting gives no persistent phase; the corrected same-epoch run is [P113-S16](P113_S16_phasing_correction.md) |
| A28 | The velocity loop, designed and tested for stability rather than assumed | python-control | P47, and it is why ADR-027 exists | RUN 2026-08-13: **four of six bands fail, and the published gain is unstable.** Bands 2, 3 and 5 were flagged in advance as able to fail and did, and band 4 failed unflagged. The loop is redesigned against margins rather than tuned |
| A29 | What air costs a ground test of exit velocity | OpenFOAM | the ground-test plan, before it is written rather than after | RUN 2026-08-13: the correction is 5.1 mm/s and two bands fail. Bands 3 and 4 point in opposite directions on tunnel size, which is the useful result: the test is not free and it is not impossible |
| A30 | Can an induction drive couple to what the satellite already has | numpy-free | PII-16, and rejects it | RUN 2026-08-13: **the rail is 22x too narrow and the drive is fine.** The entry criterion for PII-16 is not met at any pole pitch, so the architecture is rejected on geometry rather than on electromagnetics. Band 2 caught a bug in this analysis, which is why band 2 was declared |
| A31 | Does the plate stay in the gap | numpy-free | the plate drive's alignment question | RUN 2026-08-13: **it centres itself, and A30's thrust was 4.4x optimistic.** The restoring behaviour is decisive in the plate drive's favour and the thrust figure that motivated it is not |
| A32 | The entry transient and segment handover | numpy-free | the last band with a plausible chance of killing the plate drive | RUN 2026-08-13: **entry is a non-event; the segment joint is not.** Two independent models agree on entry. The handover across a segment boundary is where the remaining risk sits |
| A33 | The track's dynamic case | numpy-free | P36 | RUN 2026-08-13: six of six, and A17 was not underestimating. Band 3 is a negative result and is reported as one |
| A34 | Does the rattle settle before release | numpy-free | kill criterion 4 | RUN 2026-08-13: **it settles in 27 ms of a 146 ms stroke and leaves at zero.** The band was declared as able to fail and a failure would have been a design result; it passed |
| A45-R | The stage credit, re-read after the enclosure was itemised | numpy-free | re-reads A45 | RUN 2026-08-16: four of eight. Itemising the enclosure did not rescue the credit |
| A66 | What the drive tube costs the trim stator | numpy-free | P92, and opens P117 and P118 | RUN 2026-08-30: bands 1R, 4, 5 and 6 pass, 3 fails. The wall is 0.314 skin depths and still takes 19 % of the field, because the sheet magnetic Reynolds number decides it and the tube never moves. Band 1 as first declared could not have been passed by correct code and is withdrawn under ADR-037, with the failed run preserved at `af526a0`. The run then found that the wall takes more force than the stator makes above an air-gap field of 0.1500 T |
| A67 | The payload's guided contact state through the 8 m bore | numpy + scipy | P103, P108 | RUN 2026-08-22: six of nine. Bands 3, 5 and 7 fail and band 5 is the result: historical study misses the tip-off band by 7.4x |
| A68 | The contact law, verified, and the model-form uncertainty it carries | numpy-free | the contact law A67 assumed | RUN 2026-08-22: six of seven. Band 6 fails and it is the result: the model-form spread is 65.8 %. P111 corrected an attribution this run made to a paper that does not contain the relation |
| A69 | What shape the 8 m drive tube is actually in | scikit-fem | the centreline A67 assumed straight | RUN 2026-08-22: eight of eight. At 0 g the tube's own weight contributes exactly zero and thermal bow dominates. P110 later corrected the centreline itself, and P115 the conditioning of the solve behind it |
| A70 | Guided contact on a derived centreline and a verified contact law | numpy + scipy | re-runs A67 on A69's shape | RUN 2026-08-22: two of six pass and four are NOT EVALUABLE. *That is not a pass and it is not reported as one.* P110 then found the committed results file still holding the superseded numbers, which is why the freshness gate exists |
| A71 | A numerically converged guided-contact solution | numpy + scipy | the convergence A70 could not show | RUN 2026-08-22: two pass, three fail, three not evaluable. *The run did not converge, and that is the finding rather than a reason to withhold it* |
| A72 | How long a magnet array the shot can afford to carry | numpy-free, importing `precharged` and `tube_shielding` | the closable half of P118 | RUN 2026-08-30: bands 1 and 5 pass, 3R and 4R fail at every field by 6.8x to 44.7x. Bands 3 and 4 as first declared could not discriminate and were withdrawn **before the script existed**, which is ADR-037's rule applied early rather than late. At the array length the trim force needs, the eddy drag takes 71 % of shot work and the carriage leaves an 8.0 m tube at 0.47 to 3.30 m/s against an adopted 29.01 |
| A73 | The trim secondary derived for the annulus it is actually drawn as | magpylib, through `motor_model`'s own Lorentz integral | P117 | RUN 2026-08-30: band 1 passes on all three clauses, bands 3, 4 and 5 fail. The generalised integral reproduces `motor_model`'s own 10.5386 N per kA/m with a relative difference of exactly zero, and the curved model reproduces a flat array to 0.463 % at twenty wavelengths of radius. The section as drawn makes **56.91 N against the 948.0 N in `cad/parameters.json`**, 6.00 %, short by 16.7x -- 4.02x of it the interaction surface and 4.14x the fact that Gen5's winding lies between two arrays while historical study's lies entirely outside one. Reaching 948.0 N needs 2399 mm of array against a 12.0 mm drawn piston |
| A74 | What the tube has to become, stated as a requirement rather than a material | numpy-free, importing `tube_shielding` and `array_drag` | the part of P92 that is a calculation | RUN 2026-08-31: band 1 passes by identity at exactly 0.0, bands 3 and 4 fail. **The tube's sheet conductance must fall to 657.2 S at the remanence and 4350.7 S at 0.20 T, 1.878 % to 12.430 % of the 1.0 mm aluminium wall's 35 000 S.** A liner needs 15.01 mm inside a 7.9025 mm bore radius and fits at two of six fields; thinning the aluminium needs 18.8 um against the 160 um the gas alone requires, 8.5x below it. So all three of P92's original candidates are gone and the material has to change or ADR-033 has to yield. No material is named: E11 owns the search against the number |
| A75 | Whether the decay model is the wrong shape or just at the wrong level | numpy, importing `astro` | the calculable half of P79 | RUN 2026-08-31: six of six. **E28's two GMAT reentries invert to uniform density scales of 1.9667 and 2.4443, agreeing to 1.2428x**, so one scalar explains both and `astro.py`'s piecewise-exponential shape was never the problem -- A50 published it at mean activity, x1.0, without saying so. Checked against evidence it was not fitted to: at the calibrated band 450 km lives 195.1 to 242.5 days against the 90 it survived. Re-quoted, 400 km is **77.5 to 96.3 days**, which straddles the 90-day campaign this project quotes. The 1.2428x residual is real, is probably inclination, and is what a variable-density atmosphere would explain |
| A76 | Whether inclination through a variable atmosphere explains A75's residual | `pymsis` NRLMSISE-00, numpy around it | the named candidate in P79's residual | RUN 2026-09-15: bands 1, 3 and 6 pass, band 4 fails. **Inclination gives 1.0138x where A75's residual is 1.2428x**, the right sign and 6.3 % of it in log terms, short by 15.9x. Latitude carries almost all of that and the J2 nodal rate contributes 1.0002x. The point-wise latitude contrast is 1.109x to 1.345x, ample to explain the residual, but the gradient reverses sign with local solar time and orbit-averaging removes it. A first run that aliased its own sampling against the diurnal cycle is preserved at `f65eab3`; correcting it moved the answer by 0.0001. **P79's residual now has no named cause** |
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

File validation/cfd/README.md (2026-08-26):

# A29: the ground-test air correction

The machine flies in vacuum. The test happens in a room. Every velocity in this repository
is computed with no aerodynamic drag, and the TRL-5 step in
[`../../docs/QUALIFICATION_PLAN.md`](../../docs/QUALIFICATION_PLAN.md) fires a mass simulator
down a full 1.5 m track at sea level. Nothing said what the air was worth.

Bands are declared in [`../A29_ground_test_air_drag.md`](../A29_ground_test_air_drag.md), committed
at `949fdf4` before this directory existed.

## Running it

```
python3 build_case.py              # writes free/ and channel/ from cad/stl + motor_model
python3 build_case.py --fine       # writes free_fine/ and channel_fine/
./run.sh free                      # blockMesh, snappyHexMesh, decomposePar, simpleFoam
./continue.sh free 400 40          # 400 more iterations, writing every 40, for the average
python3 forces.py free             # drag at the latest time
python3 evaluate.py                # the bands, and the ground-test correction
python3 report.py                  # figures/A29_cfd_report.png
```

`source /usr/share/openfoam/etc/bashrc` first, or use `run.sh`, which does it.

## What is committed and what is not

Committed: the generators, the force integrator, the evaluation, the report figure and the
result JSON. Not committed: the case directories. They are a function of `build_case.py`,
`cad/stl/*.stl` and `analysis/motor_model.py`, all of which are committed, so storing them would
be storing an output of a committed input, the same reasoning that keeps `cad/` deriving rather
than pasting (ADR-015) and that governs `validation/fem3d/`.

## Four things that had to be got right

1. The geometry is the CAD, not a box. `snappyHexMesh` meshes
   `cad/stl/VOLLEY_Sled_Gen5.stl` and `VOLLEY_Payload_3U_Gen5.stl` as generated. The meshed
   wetted area is 0.4173 m² against 0.5612 m² of raw STL surface, the difference is the
   payload, sled interface, which is interior and correctly not wetted.
2. The drag force is integrated here, not read from a function object. This OpenFOAM build
   aborts `forceCoeffs` with an IOstream error before the first iteration. `forces.py` integrates
   `F = ρ Σ p Sf` over the body patch from `constant/polyMesh` and the solved field instead, which
   is a better position: every step between the solve and the coefficient is inspectable.
3. The sign convention, which was wrong first. OpenFOAM boundary normals point out of the
   *fluid*, i.e. into the body, so the body's own outward normal is `-Sf` and the force is
   `+Σ p Sf`. The first attempt used the other sign and returned a negative drag.
   `forces.py` now asserts that drag is positive, because a bluff body in a uniform stream does
   not produce thrust.
4. The work integral is over a profile, not a constant force. The shot is
   position-scheduled, `v = v_target·√(x/L)`, so `v²` is linear in `x` and the drag force is too.
   The work is `F_max·L/2`. Taking `F_max·L` would double the answer.

## Two things this reports rather than hides

The solve does not converge, and it is not supposed to. A steady solver on a massively
separated bluff-body wake plateaus and oscillates; the velocity residuals sit near 10⁻² rather
than falling. The drag is therefore averaged over a window of written iterations, and the
spread across that window is quoted with the mean. Reading a single iteration would report a
sample of the oscillation as though it were an answer.

Viscous drag is bounded, not solved. `wallShearStress` aborts in this build for the same
reason `forceCoeffs` does. Rather than reconstruct a wall shear stress from cell-centre gradients,
a second, weaker solve dressed as a first, the viscous term is a turbulent flat-plate
correlation over the wetted area, and it is labelled as a bound everywhere it is quoted. For a
massively separated bluff body it is a small fraction of the total, and the pressure term, which
dominates, is solved.

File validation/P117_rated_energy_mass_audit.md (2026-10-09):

# P117 — rated energy, kinematics and mass algebra audit

**Status:** historical-model algebraic energy ledger closes; physical source and loss validation remain open. **Evidence class:** independent calculation from the captured JSON and explicitly stated model assumptions, not a second electromagnetic solver or hardware test.

## Inputs and method

Run `python3 analysis/rated_energy_mass_audit.py`. It reads the captured [`motor_results.json`](../analysis/results/motor_results.json) and [`mass_properties.json`](../analysis/results/mass_properties.json), records their SHA-256 digests, and writes [`rated_energy_mass_audit.json`](../analysis/results/rated_energy_mass_audit.json). It does not import either production model. The equations are ordinary mass summation, $E_k=mv^2/2$, $W=Fs$, $v t/2$ for a constant-acceleration equivalent stroke, and conservation of the *reported* brake terms. Bands were set before evaluating the residuals in the script; the 1 J sled kinetic-energy band accommodates the reported 9.45 kg rounded sled mass.

| Cross-check | Result | Meaning |
|:--|--:|:--|
| Dry parts sum vs reported dry mass | 126.56 vs 126.6 kg | Rounding agrees within 0.1 kg |
| Loaded minus dry, divided by 12 | 4.000 kg per 3U | Matches the rated payload kinetic energy |
| $mv^2/2$ for payload at 16.029 m/s | 513.858 J vs 513.870 J reported | Identity agrees within 0.1 J |
| Constant-acceleration equivalent $vt/2$ | 1.30075 m vs 1.300 m powered stroke | Kinematic consistency only; not a force-history validation |
| Brake force × 39 mm | 51.787 J vs 51.798 J reported | First-order brake work identity agrees |
| Recovered energy after stated losses | 47.035 J vs 47.041 J reported | Rounded brake ledger agrees |
| Net draw | 2782.391 − 47.041 = 2735.350 J vs 2735.3 J reported | Rounding agrees |

The compact result JSON leaves **124.488 J (4.47%)** after subtracting payload and sled kinetic energies, copper heat and bank ESR. Reading the actual historical shot equations resolves that balance:

| Term in the historical model | Energy |
|:--|--:|
| 95% converter assumption applied to discrete mechanical work | 90.964 J |
| 200 W auxiliary assumption over 162.3 ms | 32.460 J |
| Forward-Euler use of updated velocity in $Fv\Delta t$ | 1.064 J |
| Remaining rounded-output difference | 0.0001 J |

The last numerical term follows $\tfrac12 m N(F\Delta t/m)^2$ with 13.445 kg moving mass, 1,623 steps and $\Delta t=10^{-4}$ s. It is an integration artifact, **not a physical energy loss**. The [energy chart](../figures/gen5_energy_accounting.svg) now shows the modelled components of gross draw. This closes only the old model's arithmetic. The 95% converter, 200 W auxiliaries, capacitor bank, winding and recovery do not have selected supplier data or independent coupled-trajectory verification. [C-05](../docs/GEN5_FREEZE_READINESS.md) therefore remains open for an installed electrical design and a force-profile rerun.

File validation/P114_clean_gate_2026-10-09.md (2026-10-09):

# P114 — recorded clean-snapshot verification, 9 October 2026

## Scope and identity

The flagship's published Gen5 evidence files were copied into an isolated Git working tree and committed as local snapshot `773c271a8c45865bd443d7c88d39b6355a1afe7f`. The snapshot predates the market-audit README addition; that addition does not change the model. The recorded run checks the saved computational record and repository gates, **not** hardware, native-solver reruns, or a supplier interface. It is not a final academic freeze.

Command, from the snapshot root:

```bash
PATH=/workspace/.venv/bin:$PATH \
MPLCONFIGDIR=/tmp/volley-mpl \
XDG_CACHE_HOME=/tmp/volley-cache \
./tools/verify_all.sh
```

Python 3.12.14; pytest 9.1.1; hypothesis 6.167.0; NumPy 2.4.6; SciPy 1.17.1; Matplotlib 3.11.1. The command exited **0**. All listed gates passed, including **148 property and regression tests**; the tracked working tree remained clean. The exact stdout is [P114 log](P114_clean_gate_2026-10-09.log), SHA-256 `bef995313f47c7734457e0d34f419b85b68fe606ccd338abed8d4d8fe96434e1`.

## What the result does not close

The companion snapshot check reported that `VOLLEY-paper` and `VOLLEY-thesis` were unavailable **inside this isolated tree**. Their published files require a separate exact-hash check. `verify_all.sh` checks captured field, circuit, CAD and analysis artifacts for consistency and freshness where defined; it does not rerun every native FEM, SPICE, GMAT or CAD solver study. Its own log says six result runs are excluded by name with reasons. The unvalidated 3-D depth-integrated force, release contact, brake, payload compatibility, host interface and full twelve-satellite campaign remain open or failed as listed in [Gen5 freeze readiness](../docs/GEN5_FREEZE_READINESS.md).

This is evidence of reproducibility for the stated gate and snapshot. Passing software checks is not independent physical validation of the Gen5 device.

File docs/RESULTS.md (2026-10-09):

> Superseded by ADR-030, 2026-08-13; annotated 2026-08-21. The audit note below is retained
> as history and is no longer the operating point. Current: 10.54 N per kA/m, 16.029 m/s,
> 10.07 g, 47.0 J recovered over a 39 mm regenerative section, 1162 J to the brake, 18.8 % net
> efficiency, and a 9.0 K per-shot brake-fin transient. ADR-030 both depth-resolved the thrust
> constant and shortened the regenerative stator from 240 mm to 39 mm, because 240 mm of regen
> plus a 300 mm eddy fin were oversubscribed in a 339 mm section (P28). Every recovery figure
> below predates that. P97.

> Numerical audit correction, 2026-08-03. The current operating point is 11.03 N per
> kA/m, 16.388 m/s, 10.53 g, 291.4 J recovered, 934.7 J to the brake, and 20.99% net
> efficiency. A13's former residual-rate/cadence conclusion is superseded, A6's 3.7e-8
> result is only a fixed-shape sensitivity, and the corrected brake-fin transient is 7 K
> per shot. Values below that describe earlier audit states are retained as history.
# Results, in charts

Everything here is drawn by GitHub from text, no image files. Every value traces to a
field in `analysis/results/*.json`, named under each chart, and nothing has been rounded
in a direction that flatters it.

These are model outputs. Nothing in this file has been measured, and only two results
carry an independent cross-check. See [`PROVENANCE.md`](PROVENANCE.md).

---

## Where the energy goes

2881 J leaves the capacitor bank per shot and 296 J comes back, so the net draw is
2585 J. 547 J of it ends up as payload kinetic energy, and that is the 21.2 % figure.

```mermaid
pie showData
    title Energy per shot (J), net of regeneration, sizing.py energy_closure
    "Sled KE to the eddy brake" : 952
    "Payload KE, the useful output" : 547
    "Copper loss, shot + regen" : 843
    "Converter loss" : 113
    "Bank ESR loss" : 94
    "Auxiliary" : 35
```

Accounted 2583 J against 2585 J net drawn, 100.0 % closure.

The regeneration credit is new and it reverses a five-year-old flat statement, so the
history matters more than the number. This page said until 2026-07-31 that the figure carried
*no regeneration credit, because the sled's 1291 J is dissipated in the eddy brake by design*.
The 2025 decision it rested on argued only that the motor cannot arrest the sled, which is
still true and still why the brake exists. It never argued that no energy could be taken back,
and nobody asked, because the previous regeneration claim had been a double-count and crediting
zero felt safe. [`../validation/A11_regen_braking.md`](../validation/A11_regen_braking.md)
asked: 240 mm of added stator returns 296.6 J, 23.0 % of the sled's energy, at the same
sheet-current rating and with peak current below the shot's own. 952 J still goes to the
brake, which is why this supplements the arrest decision rather than replacing it.

Efficiency was 32 % until 2026-07-29; adopting the CAD-derived 9.445 kg sled moved it to 20 %,
because more of the same mechanical work goes into a mass that is braked away and the longer
157 ms pulse accrues more copper loss. The ESR correction of 2026-07-30 moved it to 19 %.
Regeneration moved it to 21.2 %. Every one of those steps is a correction to a published
number, and two of the three moved it the wrong way.

A closing budget is weaker evidence than it looks, and this chart is the reason. Until
2026-07-30 it closed at 100.0 % without the 86 J ESR slice, because both sides of the ledger
omitted the same term: the draw it balanced against came from the same model that was missing
the loss. A circuit simulation with a real series resistance found the gap. Closure proves the
arithmetic is consistent, not that the physics is complete. Recorded as P24. Source:
`analysis/results/sizing.json` to `energy_closure`.

An earlier version of this project claimed 52 % efficiency by crediting 55 % of the sled's
energy back as regeneration. That was double-counting, and the correction, 52 % to 32 %, is
recorded as A25/A27 in [`INVENTORY.md`](INVENTORY.md). A11's 23.0 % is not that claim
returning, and the difference is worth being precise about: the 55 % was asserted against an
arrest architecture that throws the energy away, while 23.0 % is integrated against 240 mm of
stator that has to be built, at a rated current the winding already carries, with the copper it
burns subtracted and the brake still absorbing 952 J. It is less than half the retracted figure
and it has a run sheet.

---

## Why the conjunction claim was reframed

This is the most instructive chart in the repository. It plots the 30-day minimum
satellite-to-stage approach distance against ejection velocity.

```mermaid
xychart-beta
    title "Minimum approach vs ejection velocity, the quantity is not robust"
    x-axis "Ejection velocity (m/s)" [20.00, 20.37, 20.50, 20.65, 21.00]
    y-axis "Minimum approach (km)" 0 --> 70
    line [37.5, 4.6, 56.1, 45.3, 63.4]
```

A ±2.5 % change in velocity moves the answer by more than an order of magnitude, from
4.6 km to 63.4 km. It is a near-resonant beat sample, not a design property. The paper
originally quoted a single figure (45.3 km) as a safety result. It now rests on the
phase realignment period: 9.9 days at the current operating point, which is robust,
plus mandatory per-shot collision avoidance and host-stage disposal before first realignment.
The sweep above was computed at the superseded 20.37 m/s point and is kept as the evidence
for P1: the fragility is a property of the beat geometry, not of any one velocity.

Source: the P1 sweep table in [`OPEN_PROBLEMS.md`](../OPEN_PROBLEMS.md), computed by
`analysis/astro.py` `conjunction()`. `validation/A6_conjunction_cara.md` specifies the
quantitative replacement, probability of collision, which integrates over the covariance
instead of sampling one geometry.

---

## Payload family

Exit velocity is force-limited, so heavier classes go slower at lower acceleration. Only
the 3U case is designed; 6U and 12U are arithmetic from the same thrust constant, with no
mechanism or cassette behind them (`OPEN_PROBLEMS.md` E9).

```mermaid
xychart-beta
    title "Exit velocity by payload class (m/s)"
    x-axis ["1U", "3U", "6U", "12U"]
    y-axis "Exit velocity (m/s)" 0 --> 20
    bar [18.5, 16.5, 14.5, 13.1]
```

```mermaid
xychart-beta
    title "Modelled acceleration on the satellite (g); 25 g study ceiling"
    x-axis ["1U", "3U", "6U", "12U"]
    y-axis "Acceleration (g)" 0 --> 25
    bar [13.4, 10.7, 8.3, 6.7]
```

Every class is below the chosen 25 g study ceiling; the 1U case peaks at 13.4 g,
against 23.4 g before the CAD-derived sled mass was adopted. The machine is no longer
acceleration-limited within that model but thrust-and-mass limited. This is not a payload
qualification margin. Recovering velocity in this configuration means removing mass or raising current, not
shortening the stroke. Source:
`analysis/results/motor_results.json` to `family`.

---
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

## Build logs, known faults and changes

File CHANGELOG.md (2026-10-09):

# Change log / audit record

## 2026-10-09: finite-stator finding, R1 feeder geometry and matched reference

P118 integrated the existing 3-D analytic cuboid field through the finite 162-belt Gen5 stator. The result is 1.042 kJ ideal work and 12.448 m/s geometry-only under ideal phase, challenging the historical periodic-force 16.029 m/s shot. It is not independent FEM. Quadrature/station convergence is recorded. The [change-impact record](docs/GEN5_2026_10_09_FINDING_DISPOSITION.md) identifies every coupled shot, power, control and orbital claim that must be rerun before a corrected performance rating.

An unselected 570 mm enclosure/side-transfer R1 candidate was exported as CadQuery and native FreeCAD STEP, with exact-solid static and twelve-route swept-envelope checks. It has no lift/retention design or revised installed mass. A same-input spring/Gen5 host screen includes device mass and recoil; its sampled twelve-shot optimizer closes no option. The research result, limitations and figures were carried into the review report, thesis and IEEE-formatted manuscript while the evaluated Gen5 inputs remain unchanged.

## 2026-09-16: combined errors, reference-cell mechanics and review surfaces

I declared P113-S6 and P92-S2 in f0026a7 before implementing or executing them. S6 retains
512 conditional release-error corners. The illustrative base box passes both events, while
doubling its widths fails 20 of 64 first-event corners. Each event starts at its nominal host
state; this is not robust campaign closure. P92-S2 retains 144 linear-spring/pusher cases;
48 meet the analytical 10 g/contact screen. A zero-end-preload spring requires twice the
constant-force ideal stroke in the frictionless limiting case.

S5 freshness now compares computed event data with declared numerical reproduction floors,
retains exact sources/verdicts and regenerates presentations from the stored payload. Its
physical verification bands are unchanged. The local gate now includes S5 as CI already did.
The optional CAD runtime is pinned to the documented CadQuery 2.8.0 generation; a local
2.7.0 kernel produced different package bytes and is not used to certify artifact identity.

I recovered the useful PR36 fault-topology/burden accounting without restoring its superseded
architecture disposition. The new verification matrix records model credibility limits and
missing mission, cell and host questions. P92, P113 and E5 remain open.

Public updates repair the deployed website's out-of-root figure and document paths, add the
new studies and BOLLEY's visual review page, and synchronize the profile with the current reference.

## 2026-09-15: A76 falsifies the cause P79 named for its own residual

A75 left a 1.2428x residual between E28's two GMAT reentries, and P79 recorded the candidate in
writing: "inclination is the obvious candidate, and that is the part a variable-density atmosphere
would explain." A76 tested that sentence and it is wrong.

The premise checks out. `build_poem_campaign.py` sets R2 and R3 at the same altitude,
eccentricity, epoch, atmosphere, F10.7 and Kp, differing in `INC_DEG` alone, so inclination is the
only route a variable atmosphere has. There are two of them and A76 separated them.

| | |
|---|---:|
| Inclination delivers, NRLMSISE-00 at 350 km and the run's own indices | 1.0138x |
| A75's residual needs | 1.2428x |
| In log terms | 6.3 %, short by 15.9x |
| Of that 1.0138, from the J2 nodal rate | 1.0002x |

Bands 1, 3 and 6 pass; band 4, the one the run exists to ask, fails. The direction is right and
holds at all four quarters, so the mechanism is real and its size is not within a factor of fifteen
of the job.

**Why it is small, which the point-wise numbers do not suggest.** At fixed UT the model's latitude
contrast is 1.109x to 1.345x, ample. It does not survive because the gradient reverses sign with
local solar time, rising towards the pole on the night side and falling on the day side, so an
orbit sampling every local time averages it away. Recorded as a labelled post-hoc diagnostic that
no band depends on.

**The run's own first execution was faulted and is preserved at `f65eab3`.** It sampled two
revolutions per day, which put its step at exactly 43 200 s against a diurnal cycle and pinned the
grid to a fixed pair of local solar times, so band 5 read local-time sampling at 1.0004x, which is
what a blind grid reports rather than what the atmosphere does. The grid now walks every
revolution contiguously, 452 over 29 days at 24 points each. Correcting it moved band 4's answer
by 0.0001. The defect was real and it was not what made the band fail.

Bands were frozen at `94122ba` before `analysis/inclination_density.py` existed, and
`git show --stat 94122ba -- analysis/inclination_density.py` returns nothing. Bands 1 and 6 check
tooling and were deliberately run first; bands 3 and 4 were not evaluated in any form before the
declaration was committed.

**P79's residual now has no named cause.** What is left standing is a flag the GMAT build script
already carries beside both cases, "POEM-4-like -- UNVERIFIED" and "POEM-3-like -- UNVERIFIED":
two reference orbits not traceable to this repository, now carrying a 1.2428x disagreement with no
physics attached. That provenance is the next thing to check and it is a different kind of
question. P79's next step is re-pointed at it.

A75 is untouched, A50 band 1 stays failed, E28 stays open. `pymsis==0.13.0` is pinned in
requirements.txt and the run is in the freshness gate at a declared 1e-6, because pymsis returns
float32 and the same Fortran under another compiler cannot be held below that.

## 2026-09-15: the reading backlog is blocked by the network, not only by paywalls

P57 and E16 both need a publisher. This environment cannot reach one. `ieeexplore.ieee.org`,
`www.mdpi.com`, `arxiv.org`, `doi.org` and `api.crossref.org` all refuse with `EGRESS_BLOCKED` or a
403 from the proxy tunnel, while `pypi.org` returns 200 and git pushes succeed. Recorded as the
fourth measured limitation in `docs/REPRODUCTION_ENVIRONMENT.md`, whose previous version said "a
fourth will exist".

It is a different kind of limitation from the first three. Those made a gate fail, lie, or pass on
an eighth of the evidence. This one leaves every gate correct, because every gate here is offline
by design, and blocks work the gates were never pointed at.

**E16 narrows, on access rather than on references.** Its close condition charged all three
remaining items to publisher access. Two of them are not behind a publisher, and E16's own recorded
metadata says so: `\bibitem{eddy}` is *Actuators* under a `10.3390` DOI, which is MDPI and fully
open access, and `foster2` is arXiv:1509.03270, a free preprint. Exactly one reference genuinely
needs a subscription, `foster` in the AIAA *Journal of Spacecraft and Rockets* under
doi:10.2514/1.A33927. The reading list is the same length; the remedy for two thirds of it is any
ordinary machine.

**P57 gains a locatable citation and nothing else.** The entry named a paper by author, volume and
first page, with no title. It is *"A High Thrust Density Voice Coil Actuator With a New Structure
of Double Magnetic Circuits for CubeSat Deployers"*, IEEE Xplore document 9652065, agreeing across
two independent indexes and consistent with the volume and page the 2026-08-14 search recorded. A
DOI and an end page were offered by a generated search summary; neither is recorded, because a
summary is not one of the independent indexes E16 requires and nothing reachable from here can
check it.

No `PRIOR_ART.md` entry was written. That file records that it was first written from abstracts and
that three of its conclusions were wrong, and the paper in question is the one this project calls
its nearest published neighbour. Both entries stay LIVE; the register count is unchanged at 51.

## 2026-09-15: P56's free-baseline restatement audited surface by surface

P56 was corrected on 2026-08-14 by A21-R, and its note listed eleven public surfaces plus both
manuscripts as restated. The list was taken on trust. Checking it found twelve of the thirteen
already naming release timing at 468 s as the free baseline for in-track phase, and one that did
not.

`docs/RESULTS.md` still headed its seeding section "the actual value proposition" and priced 30°
against differential drag alone, 1.4 days against 25. The two banners at the top of that file
retire its operating-point numbers and say nothing about phase, so nothing marked the passage.
It now carries a dated correction naming the 0.0641 °/s in-track rate, 468 s to 30° at 450 km,
ADR-020's 1200 s cadence at 76.9° per shot, the 21.75 °/day drift a commanded split leaves
behind, and the +28.8 km and x1.602 that only Δv buys against x1.0000 for timing at any cadence.
The chart stays: its drag arithmetic is right, and only the comparison it implies is incomplete.

The other half of the criterion was the companion row in `analysis/comparators.py`. A21-R's R1
through R6 are present, added below A21's seven originals rather than replacing any of them, and
R2 is the row itself, time to 30° by timing over time by commanded differential, banded at
≤ 0.01. Band 3 is unedited and still reads as it passed.

With both halves met P56 classifies CORRECTED. The live register count moves from 52 to 51,
propagated to `SUMMARY.md`, `docs/CONTINUITY.md`, `docs/PROGRAMME_EXECUTION.md`,
`docs/GEN5_CLOSURE.md`, `docs/index.html`, the regenerated BSX review and the closure routing
table. No band was edited and no number moved.

## 2026-09-15: P39's provenance question answered against its own guess

P39 closed with a paragraph that guessed at its own end state: that `validation/fea/plate*.inp`
"belongs in the flagship and the solver output does not", on the strength of a sentence in
`validation/README.md` telling contributors to commit input decks. `.gitignore` had already
decided the opposite, under the comment that the decks are regenerated by
`validation/fea/build_deck.py`. The entry itself called that answering the question by accident.

Settled by measuring the generator rather than by choosing the more agreeable of the two texts.
`build_deck.py` reads three tracked files and nothing else. Run twice in the same environment it
produced byte-identical decks, 2 252 204 bytes pinned and 2 252 205 bytes clamped. Solving both
with CalculiX 2.21-1 under gmsh 4.15.2 reproduced A4's published bracket:

| Case | Reproduced | Published |
|---|---:|---:|
| pinned | 0.01945 mm | 0.0194 mm |
| clamped | 0.01600 mm | 0.0160 mm |

A deck that is a deterministic function of committed inputs carries no provenance its generator
does not already carry, so committing 4.5 MB of it buys nothing, and ADR-015's derive-never-paste
rule applies. `validation/README.md` and `docs/RELATED_WORK.md` now state the rule that way:
commit the generator where a tracked one exists, commit the deck where none does, commit result
JSON either way. What the measurement does not cover is gmsh version drift, which is why the run
sheet records mesher and solver versions beside the hashes, so a later mismatch is visible rather
than silent.

The stray files the entry was originally about were never a published copy of anything. They were
collected off a dirty working tree, which is the defect, and the `git ls-files` filter added on
2026-08-10 already prevents it.

With its last open question answered, P39 classifies CORRECTED. The live register count moves from
53 to 52, propagated to `SUMMARY.md`, `docs/CONTINUITY.md`, `docs/PROGRAMME_EXECUTION.md` and the
closure routing table. Dated audit lines in `docs/GEN5_CLOSURE.md` and the earlier
`PROGRAMME_EXECUTION.md` batch record are left at 53, because they record what was true on their
own dates. No band, no result and no Gen5 or historical study number changed.

## 2026-09-15: the public routing table misquoted eleven register titles

`docs/workstreams/ENGINEERING_CLOSURE.md` routes every live entry and quotes each native title
verbatim. Filling its owner column had been done by substitution, and the substitution reached
inside the quotes it was not supposed to touch:

| Register | Published |
|---|---|
| `An acceptance band was set ...` | `Redesignn acceptance band was set ...` |
| `At femtosat scale ...` | `Redesignt femtosat scale ...` |
| `ADR-032's first falsifier fires ...` | `RedesignDR-032's first falsifier fires ...` |
| `A65 band 4 misses A53's per-cell mass threshold ...` | `Redesign65 band 4 misses ...` |

Eleven titles across P30, P34, P44, P57, P68, P91, P94, P117, E6, E24 and E25, all restored from
`OPEN_PROBLEMS.md` rather than from any secondary copy. No status, next step, owner or count
changed; the routing still carries 53 entries.

`tools/check_routing.py` now requires every routed ID to exist in the register, its quoted title
to match that entry's heading exactly, and no ID to be routed twice. It does not check the owner
column, which is a human assignment the register has no opinion about. Wired into CI and
`verify_all.sh`, and demonstrated against a mangled title and a phantom ID.

**The gate found four of the eleven that a manual search had missed.** A pattern looking for the
substitution before a letter does not see it before a digit, which is exactly how `A65`, `A13`
and `A55` survived the first pass. That is the argument for comparing against the source rather
than searching for the symptom.

## 2026-09-15: finish the mission-study publication

- CI run 34928809087 exposed an incomplete freshness repair: scalar velocity-error
  norms and burn magnitudes still used a stricter unit-inappropriate floor than
  velocity vectors. Apply the already documented 1e-7 m/s floor to those quantities;
  retain physical acceptance, conservation checks, fuel tolerances and exact verdicts.
- Preserve the observed failures in regression tests and the incident record.
- Regenerate the mission evidence and companion snapshots after the repair, then
  verify the coherent batch before updating the main branches. Gen5 numbers,
  historical study configuration and the 53 live problem dispositions remain unchanged.

## 2026-09-15: terminal-state timing benchmark with shared comparator controls

P113-S3 declares criteria before implementation and compares three terminal circular
states over twenty release times and five assumed speed screens. Every alternative
receives the same initial and pre-release host-burn choices. Full Cartesian arrival
bands replace the energy-only criterion for this bounded single-payload benchmark.

The first independent test run rejected the circular no-transfer control. The root
unknown was changed from a near-zero correction to absolute orbital velocity, retaining
the same physical seeds, required solver success and frozen boundary residual. The
initial failed test is published with the run sheet. A best result on the latest-time
boundary does not establish an interior or global optimum. P113 and E5 remain open.

## 2026-09-14: sequential campaign allocation and architecture decision gates

P113-S2 declares criteria before implementation, then compares 180 prescribed
orbital-energy campaigns with propagated host state, changing manifest mass, burn
propellant and recoil. Fixed and adjustable spring controls remain in the comparison.
Independent Kepler propagation, event conservation, failure controls and stale-output
injection verify the bounded calculation. Complete mission feasibility is not claimed.
Implementation review replaced byte-only numerical freshness with documented tolerances
below the verification limits, retaining exact source metadata and presentation checks.

The execution record consolidates the open work and admits compact independent release
cells as a candidate alongside the magazine and gas guide. No historical study configuration,
operating envelope or provider interface is selected. P113 and E5 remain open.

## 2026-09-14: begin the host/deployer allocation trade without selecting a machine

P113-S1 declares and commits its criteria before the departure analysis exists.
The new single-event model includes finite host recoil and compares assumed release
intervals against a signed host impulse budget. Independent state reconstruction,
interval intersection and injected stale-output tests check the bounded calculation.
The speed intervals are deliberately optimistic screens, not validated operating
envelopes. No new hardware capability or full-mission resource advantage is claimed.

`docs/HOST_COMPATIBILITY.md` separates public Skyroot/Agnikul descriptions from
unavailable interfaces, adds a packaging gate and records common-path failure
questions. No company or individual endorses this study. P113 and E5 remain open;
Gen5/historical study operating points, BOLLEY's design and existing acceptance bands are unchanged.

## 2026-09-14: what a clean environment needs, recorded because two gates lied without it

`PROTOTYPE_READINESS.md` package 0 asks for environment limitations to be recorded separately,
and package 12 asks for the release evidence to be rerun from a clean environment. Nothing
covered that. `docs/REPRODUCTION_ENVIRONMENT.md` now does, from a container reset on 2026-09-14
rather than from reading the scripts.

Three measured degradation modes, and only the first is harmless:

| Missing | Effect |
|---|---|
| `numpy` and the rest of `requirements.txt` | **Loud failure** across four gates. Nobody reads a traceback as a pass |
| `cadquery==2.8.0` | **False positive.** Four STEP files reported STALE that are current -- without it the artifacts gate cannot rebuild-and-compare and falls back to the commit-time comparison its own docstring calls unreliable |
| Full git history | **False clean.** The authorship gate printed a clean line over 52 of 412 commits |

`tools/env-setup.sh` now installs past the distribution-owned `packaging` -- which otherwise
aborts the entire requirements install over one conflict -- adds cadquery with a stated reason,
and unshallows the clone when it finds one. The identity section records that neither the global
nor the per-repository git identity survives a container restart, and that the only durable
control is the gate committed to the repository.

## 2026-09-14: the authorship gate passed over a truncated history and did not say so

The gate added on 2026-09-07 reported `authorship: 52 commits, every author and committer is the
repository's own` in a working container whose clone was shallow. The repository had 412. It
passed, and it passed for the wrong reason: the sentence it prints is a claim about EVERY commit,
and on a truncated history it cannot make that claim about the ones it cannot see.

`tools/check_authorship.py` now detects a shallow clone and REFUSES rather than passing, naming
the number of commits it can reach and `git fetch --unshallow` as the fix. Both paths are
demonstrated: it refuses at 52 and passes at 412 on the same clone, before and after unshallowing.
CI is unaffected, because the workflow already fetches full history for `check_companions`.

A gate that quietly checks a subset is worse than one that refuses, because it reads as a clean
result. This is the same defect class as `check_artifacts.py`'s own note that *a false positive in
a check is a defect in the check* -- a false NEGATIVE is the more dangerous half.

## 2026-09-14: isolate artifact rebuilds (P119)

I reproduced an artifact-check defect: a CAD rebuild changed the working reference and a later
comparison could report agreement with that replacement. Rebuilds now run in temporary copies,
compare the complete file set and reuse one verdict per artifact. Four injected regressions pass.
Runtime-dependent CAD differences remain failures to reproduce, not automatic geometry changes.

## 2026-09-14: current review routes and prototype completion programme

I replaced the long README with a configuration-specific review route and current Gen5/historical study
images. The previous front page remains accessible at its exact revision. I replaced the stale
BUILD_READINESS snapshot, which still described answered items such as A52's angular-impulse
calculation as absent. No physical result, acceptance band or register disposition changes.

PROTOTYPE_READINESS.md defines the intended completion programme for VOLLEY and BOLLEY:
mission requirements, model credibility, coupled dynamics/electrics, tolerances, installed
budgets, controls, manufacturing and experiment design. The packages are planned, not claimed
complete. The current audit also found the companion payloads stale after 67939b7; they must be
regenerated before this batch is published.

## 2026-09-06: register headline gate

The register's opening table still carried superseded totals while its result JSON and other
public pages carried the current counts. The table is now generated from the same classifications
as the JSON. The check also rejects an entry whose written status disagrees with its classification.
No entry or disposition changed. The dated classifier history is retained.

## 2026-09-06: A13 verdict consistency

A13 assigned its acceptance verdicts as strings, so a changed result could retain the old
verdict. Verdicts now follow the recorded peak momentum, transient rate and endpoint momentum.
The stopped rigid-body endpoint meets row 5 immediately; a nonzero endpoint is unevaluated
without a controller. Row 7 remains void. The current run still fails rows 3 and 4. No acceptance
band has changed, and no engineering item is closed by this bookkeeping correction.

The result's inertia description still named the superseded loaded mass while the calculation
read the current mass. It now reads the same source. The offline gate checks band consistency,
source identity and that mass description. Fault injections and properties exercise the original
strict boundaries, changed inputs and unavailable settling evidence. These checks do not
establish the host inertia, flexible-body behaviour or control authority.

## 2026-09-07: the single-author claim is now enforced rather than asserted

This repository states on its front page, in `CITATION.cff` and on every companion that the work
is mine. Nothing checked it, and on 2026-08-31 a sibling repository was found carrying one commit
written under a different identity. VOLLEY escaped only because its clone happened to hold a local
`user.name` override, which is luck rather than a control.

| ID | Item | Detail |
|---|---|---|
| Gate | `tools/check_authorship.py` | Every commit reachable from HEAD must carry an author **and** a committer from a two-entry allowed set spelled out in the file rather than read from `git config` -- the configuration is exactly what failed, so reading it back would test nothing. Both fields are checked, because an identity can be laundered through the committer, which a casual `git log` does not show |
| Gate | Wired into CI and `verify_all.sh`, ahead of the link check | CI fetches full history for `check_companions`, so the gate sees every commit rather than a shallow tail |
| Verification | It passes here and it catches the case it was written for | 409 commits, every author and committer clean. Run against the sibling repository's pre-repair history it names the offending commit and the identity, which is the injected-fault standard the rest of the gate set is held to |

A provenance claim nobody checks is not provenance, in the same way a band nobody computes is not
a verdict. `check_bands.py` exists for the second reason; this exists for the first.

## 2026-09-06: BSX evidence and closure audit

The full local gate found a stale README overview that CI did not check. Regenerated it and added the overview and register-derived BSX review to CI. Contributor and provenance pages still denied the existing test suite and finite-element evidence and named the superseded licence; corrected the current guidance.

A24-R closes P54 against the current mass reference while preserving A24 failures. A2-R closes P55 by re-deriving four depth-resolved constants and recomputing all ten lever rows, preserving the previous results as history. Both were separately declared before implementation at e0a3cf611824efe19d045cab4fc73dcdfaa7abca.

Reconciled P37, P46, E29 and P95 against their already-published closing evidence. These are disposition repairs, not new experiments or changed thresholds. Gen5 retains 11 computation items and three decisions. historical study retains 18 computation items. Replaced the stale state page with a current handoff and narrowed an unsupported absolute comparison with spring deployers. Historical results and manuscript content are preserved.

Every change made to this repository after the initial export is recorded here, so that
each edit can be traced to a cause and a source of truth. This file is deliberately
exhaustive: it exists to be audited later.

Read alongside `docs/PROVENANCE.md` (what stands behind each claim), `OPEN_PROBLEMS.md` (the defect
list these changes close) and `docs/DECISION_LOG.md` (why design choices were made).

---

## 2026-08-31 (sixty-fifth pass): A75 asks the cheap question first, and the decay model turns out to be the right shape at the wrong level

P79 asked for a variable-density atmosphere. Before writing one, A75 tested whether the model's
*level* explains the disagreement, and it does.

| ID | Item | Detail |
|---|---|---|
| A75 | **E28's two GMAT reentries invert to uniform density scales of 1.9667 and 2.4443** | They agree to **1.2428×** against a band that asked for a factor of two, so one scalar reproduces both. `astro.rho` already carries eleven base altitudes with their own scale heights; its shape in altitude was never in question. **What A50 published was that table at mean activity, ×1.0, and it did not say so** |
| A75 | Checked against evidence it was not fitted to | The 450 km case was a one-sided fact, not a fitting point. At the calibrated band a 450 km satellite lives **195.1 to 242.5 days** against the 90 it survived, and on its own that case would have permitted any scale up to 5.3093. A50's altitude monotonicity holds at both ends of the band |
| A75 | The headline becomes a range, which is what P79 asked for | 350 km **29.0 to 36.0 d**, 400 km **77.5 to 96.3 d**, 450 km **195.1 to 242.5 d**, 500 km 461.6 to 573.7. *"450 km buys months"* is 6.4 to 8.0 months. **The 400 km row straddles the 90-day campaign this project quotes**, which the single number could not say |
| A75 | The residual is kept rather than explained away | Two cases at the *same altitude* need *different* scales, which a scalar cannot carry by construction. Inclination is the obvious candidate. P79 stays LIVE and stays `COMPUTATION` for it: the question has shrunk from 2.4× to 1.24×, not disappeared |
| A75 | Three ways of over-reading it, closed off in the run sheet | **A50 band 1 stays failed** — it asked for ≤ 60 d and got 70.6, and a calibration after a band fails does not reach back. **P16 is not rescued** — a uniform scaling preserves a lifetime ratio by construction, which is precisely why P16 withdrew the invariance claim. **It is not a measurement** — GMAT is a second model |
| A9 | Re-tested today, and still not runnable | CelesTrak is still refused by this environment's egress proxy under organisation policy, exactly as A9 recorded when it was written. The repository still has no comparison against a flown object. E4 stands, for the same reason it did in July |
| Gate | A75 is **in** the freshness gate, and the reason is measured | `astro.lifetime` advances in `int()`-quantised chunks, the hazard that made that gate numeric in the first place. Perturbing the density scale by one, two and four ulp and the ballistic coefficient by one moved the 350 km lifetime by **exactly zero** in all four cases, so it is gated at the default tolerance rather than excluded |
| Counts | 75 run sheets, 72 analyses | Register unchanged at 153 entries, 59 live |

---

## 2026-08-31 (sixty-fourth pass): A74 states the tube as a requirement, and P92 becomes a decision

Four runs in two days have taken P92 from *nobody has computed what the tube costs* to *here is
the number the tube has to meet, and here is why no local fix meets it*.

| ID | Item | Detail |
|---|---|---|
| A74 | The requirement, and no material named | **The drive tube may carry 657.2 S at the remanence to 4350.7 S at a 0.20 T air-gap field — 1.878 % to 12.430 % of the 1.0 mm aluminium wall's 35 000 S.** At 0.60 T it is 1446.3 S, A72 band 6's number to the digit, which is two inversions of the same model meeting from opposite ends. No new material data enters the run and E11 owns the search against it |
| A74 | Band 1 is an identity, not a cross-check, and says so | The file imports `tube_shielding` and `array_drag` rather than re-deriving them, so agreement would prove nothing about the physics. What it checks is that the import is live: the break-even field and the worst force-over-parity ratio reproduce the committed values at exactly 0.0. A stale import is the failure mode this run actually has |
| A74 | **Band 3 fails and P92's third candidate goes** | A liner needs **0.59 mm at 0.20 T and 15.01 mm at the remanence** against a 7.9025 mm bore radius, fitting at two of six fields. It buys one power of `exp(-kt)` and not two, because it moves the magnets away from the winding as well as from the wall — 12.3 % per millimetre on the ratio, not 23 % |
| A74 | **Band 4 fails and the wall is not a free variable** | Thinning the aluminium alone needs **18.8 µm** against the 0.16 mm A59 says the gas alone requires — 8.5× below the pressure floor and 53× below the 1.0 mm as drawn |
| A74 | Band 5 supplies the number ADR-035 did not have | Steel is **+2.154 kg** on a shared tube, **+0.1795 kg per satellite**, taking A73's 1.6050 kg to 1.7845 kg against a 2.0 kg ceiling. ADR-035 chose aluminium on mass alone and was right on the questions asked of it. **The mass it saved is affordable to give back** |
| A74 | A band whose wording admitted two readings, recorded as such | Band 3 did not say whether the liner had to work at *some* field or at *every* field. The implementation takes the strict reading and the run sheet prints both counts, because the loose reading would pass in the corner where the secondary makes 18.37 N against a 948.0 N specification, and a band that passes where the machine makes nothing tests nothing |
| **P92** | **Moved from `COMPUTATION` to `DECISION`, and the move is argued rather than taken** | On 2026-08-30 this entry stayed `COMPUTATION` and said explicitly that relabelling it would take one off the closure count for no work. The work has since been done: four run sheets, two with failing bands, and every local fix eliminated by calculation. What is left is which of ADR-033 and ADR-035 yields, and no analysis settles that. historical study remaining COMPUTATION 19 → 18, DECISION 0 → 1, and `docs/COMPUTATIONAL_CLOSURE.md` carries the reasoning beside the count |
| Index | The gate added yesterday caught its first real omission within the hour | `check_links.py` failed on A74's run sheet having no row in `validation/README.md`, before the commit was made |
| Gate | A74 excluded from the freshness gate by name | Twelve nested root-finds over A72's own root-find over the shot integration |
| Procedure | `check_companions.py` gains the thing that keeps reddening CI | The export record can only name a commit that already exists, so it is always the commit after. Four CI runs failed on that gate in two days, each of them right, each on a push made before the export. Push once per unit of work with the export record last |

---

## 2026-08-30 (sixty-third pass): A73 derives the constant A55 borrowed, and the trim force is 6 % of what the parameter file says

A66 bounded it and stopped, because bounding a number is not deriving it. A73 derives it.

| ID | Item | Detail |
|---|---|---|
| A73 | The verification that makes the rest usable | The Lorentz integral `motor_model.thrust_constant()` performs is generalised to take the field and the cross-section as arguments, and handed Gen5's own flat field it returns Gen5's own constant — **10.538611491665296 against 10.538611491665296, a relative difference of exactly zero**. No phase convention, no factor of two in a time average and no normalisation is re-decided between the machine the constant was measured on and the machine it was applied to |
| A73 | The curved geometry checked against a limit, not against a second approximation | At a bore radius of twenty wavelengths the annular model reproduces a flat single-sided array to **0.463 %**, and doubling the angular sectors moves the peak field by **0.1037 %** |
| **P117** | **The section as drawn makes 56.91 N against the 948.0 N in `cad/parameters.json`** | **6.00 %, short by 16.7x.** About 4.02x is the interaction surface — 306.0 cm² of flat array against 76.03 cm² of annulus — and 4.14x is chiefly that Gen5's winding lies between two arrays while historical study's lies entirely outside one, with its outer copper where the field has fallen to 45.6 % across the 6 mm belt |
| P117 | Two failures that came with it | Reaching 948.0 N needs **2398.9 mm** of magnet array against the **12.0 mm** piston `build_legacy_study.py` draws, 200 lengths of the part it would live on. And the array is on the carriage, which ADR-035 records is not recovered — *"each of the twelve satellites has its own"* — so it is added **undivided**, unlike the shared stator section `trim_authority.py` divides by twelve: 1.6050 kg per satellite as drawn, 6.44 kg at the length 948.0 N needs, against a 2.0 kg ceiling |
| A73 | Band 6, the one thing on the design's side | A convex array at this radius concentrates its own field **1.25x** over a flat array of the same depth and standoff. Reported, not banded: the difference is physical and ADR-037 forbids a tolerance on a gap of that kind. The standoff is matched exactly, because the first version of this file compared 0.6 mm against 0.5 mm and put an `exp(-k dz)` of 1.3 % inside a number whose whole purpose is to be honest about a 25 % effect |
| P117 | `cad/parameters.json` is **not** edited, and the reason is written down | Correcting `force_N` moves the section length, the peak power, the correction energy, the CAD and A55's own bands — a re-run of A55, not an edit — and A72 found the same day that the architecture it would re-size is falsified. The wrong number stays visible with P117 attached rather than quietly replaced. P92's trade first, then A55 |
| Index | `validation/README.md` was nineteen rows short and said so nowhere | It opened by describing *"nineteen of the twenty-one below"* while the directory held 73 files, and every run from A66 onward was missing. Every file now has exactly one row, and `check_links.py` gates it: a deleted row, a phantom entry and a duplicated row are each caught, demonstrated by injection. `check_public.py` counted run sheets and never checked whether they were listed |
| Gate | A73 excluded from the freshness gate by name, with the reason | Ten minutes of magpylib over 720 cylinder-segment sources |
| Runs | Two runs of A73 discarded before the one recorded | One died serialising a numpy boolean; one compared band 6 at mismatched standoffs. Neither produced a number that is used, and both are named rather than left out |
| Counts | 73 run sheets, 70 analyses. Register unchanged at 153 entries, 59 live | A73 answers an entry that was already numbered |

---

## 2026-08-30 (sixty-second pass): A72 integrates the drag A66 found, and two adopted decisions turn out to exclude each other

A66 could not integrate the brake it discovered, because the magnet array is dimensioned nowhere
in this repository. A72 makes the length the variable instead of waiting for one.

| ID | Item | Detail |
|---|---|---|
| A72 | Bands declared before the script, then two of them withdrawn before the script, then the script | `3f70082` froze six bands. `0abbe1b` withdrew bands 3 and 4 as unable to discriminate and froze 3R and 4R in their place, **with no result in existence**: band 4 could never fail, because the drag vanishes with velocity while the gas force never falls below the seal friction — 445.88 N at the breech, 198.15 N at the muzzle, against 83.4 N — so any carriage always reaches the muzzle. Band 3 failed at zero array length, because 29.01 m/s already has the whole 28.3887 % friction allowance subtracted from it. ADR-037's rule applied one run later and this time *before* the script |
| A72 | Three lengths at each field, and no favourable end of the ladder | The array that makes the section's 948.0 N is **6.8× to 44.7×** longer than the array whose drag costs what the seal friction costs, and **5.6× to 36.9×** longer than the array that stops the carriage accelerating. At the length the force needs, the eddy drag takes **71 % of shot work** and the carriage leaves an 8.0 m tube at **0.47 to 3.30 m/s** against an adopted 29.01, decelerating. A weaker magnet needs a longer array and the drag scales with the array, so the ratio gets worse as the field falls |
| A72 | Band 5 is the one that makes it hard to dismiss | Halving the conductivity, halving the wall, and doing both leave all four verdicts unchanged. The finding is not sitting on a handbook conductivity or on a wall thickness chosen for handling |
| A72 | Band 6 puts a number in P92's fix trade | The wall's sheet conductance would have to fall to **1446.3 S**, 4.132 % of the 1.0 mm aluminium wall's 35 000, or 1.4463e6 S/m at that thickness. That lands within a few per cent of austenitic stainless, which is a boundary and not a solution: A63 already priced steel at +2.154 kg, and three per cent against a handbook value at room temperature is not a margin |
| A72 | Two coding defects, found before the result was believed, neither a band | The shear check was wired to the reduced field rather than the incident one, double-counting the transmission by `1/(1+Rm²)`, 36.2 % at this point — band 1 caught it. And neither the drag energy nor the worst acceleration is monotone in array length, because the drag goes as `v·L` while `v` falls roughly as `1/L`; a plain bisection returned its own upper bound as an answer for three of six fields, and the shortest crossing is now found by scanning first |
| P118 | Integrated, and the fix handed to P92 rather than duplicated | The entry stays LIVE and stays `COMPUTATION`. What is left is the trade P92 owns, now with A72's number in it |
| Gen5 | Untouched, and the run sheet says so | The Phase I machine is a flat ironless stator with no tube and no conducting member between the winding and the array. Nothing in A72 reaches `docs/BASELINE.md` |
| Gate | A72 excluded from the freshness gate by name, with the reason | 44 s of root-finding over an integration, which is the A67 and A68 case. An exclusion that is not written down is a gap |
| Counts | 72 run sheets, 69 analyses | Register unchanged at 153 entries, 59 live: nothing here is a new defect, it is the answer to two that were already numbered |

---

## 2026-08-30 (sixty-first pass): A66 runs, and it answers a bigger question than it was asked

P92 asked what the aluminium drive tube costs the trim stator. The answer to that is 19 % of
authority, and 34 mm more section buys it back. Then the same model said something the bands
were not written to catch.

| ID | Item | Detail |
|---|---|---|
| A66 | The run, preserved with its faults before any of them were corrected | `af526a0` is the run as it executed against the bands frozen in `e05551b`. It failed band 1 at 1.4874 % against 0.5 % and band 3 at 0.9356 m/s against 1.1543, and its loss model was wrong by a factor of two. Nothing about it was cleaned up |
| ADR-037 | Band 1 could not have been passed by any correct implementation, so it is withdrawn rather than widened | Holding the sheet conductance fixed and shrinking the wall, the slab converges on the sheet at exactly first order across three decades — 1.487 % at 1.0 mm, 0.001581 % at 0.001 mm. Both routes are therefore right, and 1.4874 % is the thin-sheet truncation error at `kd` = 0.131. A 0.5 % tolerance sat underneath a number the geometry fixes. The declared row is not edited |
| A66 | Band 1R, frozen in its own commit before the script was touched again | Limits and convergence order rather than the size of a cross-method gap: zero-σ transmission exactly unity and exactly `exp(-kd)`, agreement within 0.01 % at a 1e-3 mm wall, and every pairwise convergence order first order to within 0.05. It passes at 0.0436. It is a harder gate than the one it replaces |
| A66 | A factor of two in the loss model, found in review and not by a band | Peak-amplitude phasors dissipate `\|K\|²/(2σd)`, not `\|K\|²/(σd)`. The tell is that the faulted version implied a shear three times the Maxwell bound `B²/2μ₀`, which nothing can do. That bound is now computed on every run; the corrected result sits at 0.9906 of it, which is where a sheet at `Rm` = 0.754 belongs |
| A66 | The air-gap surface is an annulus, and I had used the flat Gen5 array's depth | 90 mm is `stator.active_width_y`, the depth of the Gen5 flat array. The historical study trim section is an annulus around a 15.805 mm bore and `cad/build_legacy_study.py` has always drawn it as one. 76.03 cm², not 129.61 |
| **P117** | **NEW, HIGH. The section's force needs a field above its own magnets' remanence** | `trim_stage.py` sets it from Gen5's lumped thrust constant, which A2 defines over `SLED_ACTIVE_LEN` = 0.34 m of flat array 0.09 m deep. A55 applied it to 0.14401 m of annulus, unrescaled for length or area. Over the real surface, 948.0 N at 90 kA/m needs **1.3854 T** against `motor_model.BR` = **1.32 T** |
| **P118** | **NEW, CRITICAL. The wall takes more force than the stator makes, and it does it for the whole stroke** | `drag / thrust = σdvB_net/2K` carries no area, no section length and no thrust constant, and it reaches one at **B_net = 0.1500 T**. Every field a permanent-magnet array produces is above it: 1.08 at 0.2 T, 3.24 at 0.6 T, 7.13 at the remanence. And the magnets ride the carriage, so they face the wall for all 8.0 m and not only the 144 mm under the stator. The magnet array's length is not in `cad/parameters.json`, so that integral cannot be closed yet |
| P92 | Answered, not closed, and it stays `COMPUTATION` | The comparison P92 named — the wall against the skin depth — is not the one that governs. The wall is 0.314 skin depths and removes a fifth of the field, because `Rm` = 0.7539 decides it and the tube never moves. Relabelling the entry `DECISION` would have taken one off the closure count for no work, which is the one failure that gate exists to catch |
| A66 | The wall temperature is reported without a gate, and the gap is stated rather than filled | I declared no band against the 473 K ceiling. The ceiling is crossed near 0.8 T, every campaign stack assumes the heat stays where it was made for four hours, and the axial diffusion length over ADR-020's 1200 s cadence is 287.8 mm — twice the section. The per-shot column is the part I would defend |
| Counts | Register 153 entries, 59 live. 71 run sheets, 68 analyses. historical study remaining COMPUTATION 17 → 19 | A66 is written, so it comes off the "numbered and never written" list in `README.md` |

---

## 2026-08-30 (sixtieth pass): the solver chain runs here again, and A4 reproduces

`tools/env-setup.sh` has named `calculix-ccx` and `ngspice` since it was written. Neither was in
this container, so the structural and circuit runs could be reproduced only on a GitHub runner.
For a repository whose argument is reproducibility that is the wrong way round, and it went
unnoticed because no gate re-runs them.

| ID | Item | Detail |
|---|---|---|
| Toolchain | CalculiX, ngspice, gfortran and qpdf installed, and each shown to work rather than merely to exist | ngspice reproduces the RC step at one time constant as 6.321204e-01 against an analytic 1 - 1/e = 0.632121. CalculiX solved both A4 decks |
| A4 | The structural run reproduces its published numbers on this machine | `validation/fea/build_deck.py` rebuilt both decks from `EMOCD_Sled_Gen3.step`, 3672 N over 340 x 90 mm, and CalculiX returned a peak airgap closure of 0.01945 mm pinned and 0.01600 mm clamped. The run sheet publishes 0.0194 and 0.0160. The bracket is reproduced, not asserted |
| Deps | `requirements-dev.txt` added, and the test harness moved into it | Nothing in that file produces a number that appears in the repository; it tests, cross-checks and lints the code that does. `requirements.txt` keeps the four packages the published numbers depend on. Versions are read from the environment rather than chosen, because a pin invented from memory is a made-up number like any other, and the first draft of this file had five of them wrong |
| Deps | Independent-check tooling, installed for a stated purpose | astropy, skyfield and sgp4 to cross-check the hand-rolled orbital model rather than replace it. mpmath and sympy to re-derive a suspect figure by another route. scikit-fem and meshio for a structural path independent of CalculiX. jsonschema for the results contract, so a renamed field fails a gate instead of a downstream read. pypdf and pdfplumber for the numbers inside a generated PDF. Pint is deliberately absent: the recent defects were same-unit semantic errors and a dimensional checker would not have caught one of them |
| CI | The workflow installs both requirement files | Otherwise the test gate added last pass would pass locally and be absent on the runner |

---

## 2026-08-30 (fifty-ninth pass): the verification that was thrown away every time is kept

Eighty-one analysis files, seventeen thousand lines, and exactly one of them carried a
self-test. There was no test runner and no `tests/`. Every fault injection this repository
has ever run -- nine against the document gate, nine against the freshness gate, four
against the P116 identities, three against the seed-path check -- was written in a
throwaway script, proved the fix on the day, and protected nothing afterwards. That is how
P114 and P116 came to be the same mistake twice.

| ID | Item | Detail |
|---|---|---|
| Tests | `tests/`, run by `verify_all.sh` and by CI | Thirty-one tests in three files, plus a README that says what they do not do. Not a replacement for a run sheet: bands in `validation/` are still the only place a claim is earned against a criterion declared before the script existed |
| Properties | Rules that must hold for ANY input, generated by hypothesis | The thirty-five identities in `host_reference.self_test()` check one altitude and one stage mass. P114 was a claim that is true at 500 km on a 1000 kg stage and false in general, and nothing evaluating only the reference point can tell those apart. Nine orbital properties and nine campaign properties now range over 200 to 2000 km and 400 to 3000 kg: a single impulse always out-raises the same dv spent as a complete transfer, a prograde impulse never moves perigee, the Hohmann inversion round-trips, burn duration scales exactly as one over thrust, every main-engine impulse reaches the floor and every impulse below it is assigned away, each leg starts where the last ended, a propagated campaign always reaches at least the naive multiple, and raising either the burn floor or the thrust never makes a case more executable |
| Regressions | Every shipped defect, reintroduced, with a gate required to catch it | P116 in both directions, the multiplied campaign duration, the campaign that never leaves its start orbit, the accounting that drops the auxiliary half, an edited value inside a generated block, a removed block marker, a one-ulp drift tolerated beside a factor-of-15.6 staleness caught, a flipped band verdict, a removed key, and the dead `$B` path in the issue seeder. Each asserts a failure list is NON-empty, so it fails when the defect stops being caught. A control test asserts the self-test passes when nothing is broken, without which the rest would pass against a self-test that always fails |
| Mutation | The suite is checked against the real source, not trusted | Halving the apogee rise, inverting the burn-floor comparison, disabling sequential propagation and perturbing burn duration by one per cent each turn it red, and it returns green when the source is restored. A test suite that has never been shown to fail is a claim, which is the same standard the document gate was held to |
| Identity count | Now recomputed independently in a test | It printed "25 identities hold" while the function held more. The count is read from the source at run time and a test recomputes it a second way and requires agreement |
| Deps | `pytest` and `hypothesis` are hard dependencies, not optional | `verify_all.sh` skips them with a stated reason rather than silently if they are absent, because a gate that disappears when a package is missing is worse than no gate |
| Gate | The companion gate accepted an export commit that no fresh clone would have | It asked `git cat-file -t`, which says the object exists in THIS clone. That stays true for a commit amended or rebased away: the object lingers locally and was never fetched anywhere else. The gate now also requires the recorded commit to be an ancestor of HEAD, which is the property that travels. It was found by causing it, amending a commit after running the exporter, and it is the same shape as the `59b3661` record that was failing on `origin/main` at the start of this session |

---

## 2026-08-30 (fifty-eighth pass): branch cleanup, and a dead link the gate was built not to see

Trimming the repository's branches turned up one real defect and one blind spot behind it.

| ID | Item | Detail |
|---|---|---|
| Link | `tools/seed_issues.sh` pointed at `docs/PHASE_II.md`, gone since VAULT-01 | That rename moved the file to `docs/VAULT.md` and retargeted twenty-one files. This one was missed, and the text is issue-seeding copy, so the dead link would have been published into a GitHub issue body where nobody re-runs a link checker. Repointed to `docs/VAULT.md`; PII-4 is still there and still the envelope-repackaging entry the issue means |
| Gate | `check_links.py` excluded the file it was in, so no gate could ever have caught it | The exclusion was written for relative link-shaped strings inside generators, which resolve in the file they are written into rather than in the generator's own directory. It swept up `seed_issues.sh` with them. But `$B` is the flagship base URL, so `$B/<path>` is an ABSOLUTE flagship path and does resolve against this checkout. Those paths are now checked, the comment says why they are different, and two injected faults confirm it fails on a renamed target and on a path that never existed. Four other `$B` targets in that file resolve |
| Branches | `ci-diagnostic` is cleared for deletion but could not be deleted from here | It sits at `ef1878f`, a strict ancestor of `main`, so it carries nothing to merge and removing it loses nothing. The deletion itself did not happen: this environment reaches GitHub through a proxy that terminates a push carrying no packfile, which is exactly what a delete refspec is, and four attempts failed identically. `git push origin --delete ci-diagnostic` from an ordinary clone will do it. The branch existed to prove that this repository's Actions settings refuse any workflow referencing a third-party action, which the fifty-fifth pass recorded and fixed |
| Branches | Two local-only refs dropped | `pre-public-sync-2026-08-22`, fully contained in `main`, and `pr16`, the pre-rewrite history rooted 2026-07-29 with no common ancestor with `main` at all. Four files existed only there and all four were checked before the ref was dropped: `docs/PHASE_II.md` is `docs/VAULT.md` now, `tools/export_portfolio_repos.py` is superseded by `tools/export_companion.py` which covers all three companions rather than the old three portfolio copies, and the two CAD briefs describe a Fusion 360 and AutoCAD workflow for a Fusion-authored Gen3-era model. The published Gen5 renders come from Blender on the STLs `build_gen5.py` writes, which is a different pipeline, and no 2D drawing set was ever produced from the AutoCAD brief. Nothing was carried across |

---

## 2026-08-27 (fifty-seventh pass): the mission cases could not be flown by the engine that was billed for them

A second independent review of the host-reference study, one day after the first. Three defects.
The first reverses the study's headline conclusion for the second time in two days, and it runs
opposite to the error P114 corrected: that one understated what the engine was asked to do, this
one credited the engine with manoeuvres it cannot perform.

| ID | Item | Detail |
|---|---|---|
| P116 | HIGH. Case B and Case C counted main-engine ignitions for impulses below the file's own minimum burn | Numbered under [ADR-021](docs/adr/021-freeze-the-register.md) rule 2. Section 10 computes that a 2 s burn on the 1000 kg reference stage at 20 kN is a 40.27 m/s command; section 11 then modelled 20 m/s and 40 m/s legs, whose individual impulses are 0.49 s and 0.94 s. Not one of the sixteen reaches the floor. The file published 7 and 11 post-primary ignitions, called the excess over the assumed budget of 4 its sharpest finding, and ranked restart count as the most valuable provider datum. All three followed from charging the engine for manoeuvres its declared envelope forbids. Every impulse is now checked and assigned to `MAIN_ENGINE` or `AUXILIARY_PROPULSION_REQUIRED`, three branches price what can actually be flown, and the hierarchy puts minimum impulse first and restart count second |
| Propagation | Sequential campaign altitude was a multiplication | Each leg was solved from 500 km and the first leg's raise multiplied by the leg count, published as "cumulative raise": 399 km over eleven legs. The same total dv buys more altitude from a higher orbit, so the campaign ends higher than the multiplication says. Propagated leg by leg, eleven legs reach 915.5 km, a net rise of 415.5 km, and the old figure was 3.9 % low. Mass propagates too, which is what makes the minimum commandable step grow along a campaign. Not numbered: an approximation error in an illustration, in the conservative direction, that reversed no conclusion |
| Pacing | Campaign duration was the first leg's arc times the leg count | The transfer ellipse grows with the orbit, so the arcs lengthen. Summed properly, Case C moves from 3.97 to 4.10 h and an eleven-leg campaign from 8.71 to 9.06 h. Not numbered, same reason |
| Branches | Three branches replace one infeasible reading | Branch 1, main engine only: the smallest shell change whose *each* impulse reaches the floor is 150.4 km and 81.9 m/s from 500 km, growing to 182.3 km by the fourth leg as the stage lightens, four steps inside the 120 kg customer allocation, ending at 1163.3 km. Branch 2, main engine plus auxiliary: every reposition impulse falls to auxiliary propulsion and the main engine performs only the 4.41 s disposal burn, leaving a demand of 60 m/s across six impulses for Case B and 200 m/s across ten for Case C, with no auxiliary capability assumed anywhere. Branch 3, hypothetical throttle: 24.5 % of baseline thrust for Case B and 46.8 % for Case C, marked a sensitivity and not a claim that any engine throttles |
| Architecture | The three-way split is now reached from both ends | Section 10 arrives at main engine coarse, auxiliary fine, VOLLEY for release from the fine end. Branch 2 arrives at the same split from the campaign end, independently. Two arguments landing on one architecture is worth more than either alone |
| Provider data | The engine rows are reordered by what actually decides the mission | Minimum stable burn, then minimum thrust and throttle envelope, then full-engine restart count, then vacuum thrust, then Isp, then restart dwell. The first two decide whether the main engine can command the required impulses at all; restart life matters after that. The earlier ranking put restart count first, which followed from the ignition count P116 corrects |
| Self-test | Ten identities added, guarding the corrections in both directions | An impulse marked executable must reach the floor and an impulse below the floor must be assigned away from the engine; leg *n* ends where leg *n+1* starts; net rise is the propagated difference and never below the naive multiple; duration is the sum of the arcs; main-engine and auxiliary counts equal what was assigned and add to twice the leg count; lowering the floor cannot reduce executability and a zero floor admits everything; raising thrust at a fixed floor cannot increase it; branch 1's binding impulse reaches the floor exactly |
| Self-test | The identity count was hardcoded and had gone stale | It printed "25 identities hold" while the function held more. It is now counted from the source at run time, which is the same staleness the results-freshness gate exists to catch, one level up |
| P114 | Superseded in part, not rewritten | Its ignition arithmetic stands: a shell change is two impulses and disposal is a third ignition. The conclusion drawn from it does not, and the entry now says so and points at P116. Retained as the published record |
| P113 | More important, not closed | Stays `PROGRAMME`, `COMPUTATION`, `LIVE`. If a host main engine cannot perform fine shell changes, dividing orbital work between host, auxiliary propulsion and deployer is a harder problem than the file made it look, not an easier one |
| P108 | Untouched | The historical study design point stays at 29.009 m/s. Nothing in this pass lowers a VOLLEY requirement, and the assumed 4-ignition budget stays a `VOLLEY_ASSUMPTION` wherever it appears rather than becoming an engine figure |
| Sources | Two retrievals re-attempted, both still blocked | The specific turbopump article and a company-owned ignition post were re-attempted on 2026-08-27. Both return a 403 at this network's own proxy, before the publisher is reached. No row is promoted to `COMPANY_PRIMARY`, every claim keeps its `SEARCH_SUMMARY` mark, and the file now says that S2 is cited by article title against a landing-page URL because the article-level URL could not be confirmed from here |
| CI | The drift step still demanded byte identity of floating-point output | It regenerated `host_reference.json` and ran `git diff --exit-code`, and on a GitHub runner the transfer-arc sums came back one ulp apart: 143.62078713217508 against 143.6207871321751. `pow` and division are not required to be correctly rounded, so that disagreement is irreducible and is the same class as P115. The file was already being regenerated and compared numerically by the freshness gate one step earlier, with a declared tolerance and a reason, so the byte comparison was a second and incompatible standard applied to the same file. It is removed from the drift step in both the workflow and `verify_all.sh`, with the reason written beside it. The generators that remain there emit integers and formatted text, where byte identity is achievable |

---

## 2026-08-26 (fifty-sixth pass): the penalty supports in A69, and a wrong diagnosis withdrawn

The fifty-fifth pass ended by setting a per-file reproducibility tolerance on two results files
and explaining the wider of the two as cancellation in a sagitta. That explanation was wrong.
Running the gate a second time on a runner, with the disagreement reported field by field,
named A69's own fields rather than A70's, and at 8.5e-4 rather than 1.3e-4.

| ID | Item | Detail |
|---|---|---|
| P115 | MEDIUM. `tube_centreline.beam()` held its rigid supports with a 1e8 diagonal penalty, at cond 8.6e15 | Numbered under [ADR-021](docs/adr/021-freeze-the-register.md) rule 2. The penalty satisfies the constraint to 1e-17 m and destroys the interior of the solution: against a double-precision epsilon of 2.2e-16 there is nothing left along the worst direction. Only the cases with a prescribed support OFFSET moved, because only those put the penalty into the right-hand side as well as the diagonal, which is exactly the set of fields the runner named. The supports are now imposed by eliminating the constrained rows, cond 4.1e9. A69's support-placement peak goes 0.0768 to 0.0769 mm; every band verdict in A69 and A70 is unchanged and A70's printed sagitta map does not move at all |
| Diagnosis | The cancellation explanation is withdrawn | It attributed the cross-machine disagreement to A69 reproducing at 3e-9 and a three-point sagitta amplifying that by about 33,000. The amplification is a real property of a sagitta; it was not what happened. A70's sagittas moved by 5e-5 against an input that moved by 8.5e-4, which is less than their input rather than 33,000 times more, and the local 3e-9 was a same-machine re-run that could not see conditioning at all |
| Tolerance | 1e-3 on `guided_contact_derived.json` is withdrawn with it | It was set on the withdrawn reasoning and it would have passed the gate with the defect still in place. Both files now carry 1e-7, measured by perturbing every entry of the matrix and the right-hand side by one ulp and re-solving: the penalty formulation spreads by 4.3e-3 and the eliminated one by 4.4e-8. The observed 8.5e-4 sits inside the first and five orders outside the second |
| A69 | `free_free_first_mode()` picked the rigid-body modes by sign | A free-free beam's two rigid modes are zero; discretisation puts them at 1.1e-4 and 4.5e-4 against 110.5 for the first elastic mode. Keeping the eigenvalues above zero and dropping the first two means a numerically-zero eigenvalue landing a hair below zero on some other LAPACK is discarded, the slice moves by one, and the function returns the SECOND elastic mode at 2.76x. Under a one-ulp perturbation the sign filter moved by 1.76 relative and selection by magnitude by 2.0e-6. Not numbered: this machine and the runner both picked the right mode and 1.6729 Hz is unchanged, so nothing published was wrong |
| Gate | Three leaves carry their own tolerance instead of loosening a file | The free-free mode at 1e-5 relative, and the two `err_pct` residuals at 1e-5 absolute. Those two are 3.4e-7 and 2.3e-6 PERCENT -- differences of numbers agreeing to fifteen digits, with no significant figures to reproduce -- and band 1 tests them at 0.5 %. Nine faults were injected to check the arrangement, including one that substitutes the second elastic mode for the first |
| Gate | The freshness gate left its own output in the working tree | It re-runs a script, compares, and on a pass left the regenerated file in place. On one machine that is byte-identical and invisible; on a runner it is a real difference, and CI's next step -- `git diff --exit-code` after regenerating the generated documents -- failed on a file this gate had written rather than on anything that had drifted. It now restores the committed file after every comparison, pass or fail. A checker that leaves its output behind is a generator |
| Gate | The document gate's coverage is now stated in the document | The markers hold the tables and the tables are 12 per cent of the file. Three further faults were injected at the edge -- a figure, a unit and a verdict word altered inside a sentence rather than a block -- and the gate passes all three. That is the surface P114 lived on: a correct total in a table with a sentence beside it reading that total as one burn. The file now says so instead of leaving the reader to infer the gate covers more than it does |

---

## 2026-08-26 (fifty-fifth pass): the host-reference study is audited, and its orbital model was wrong

An independent review of `docs/HOST_REFERENCE_CASES.md`, on the day it was published, found six
defects. One is numbered under [ADR-021](docs/adr/021-freeze-the-register.md) rule 2 as a model
error that made a published document wrong. The other five are claim withdrawals, a missing
sweep, a weak gate and an infrastructure fault, none of which that ADR permits into the register.

| ID | Item | Detail |
|---|---|---|
| P114 | HIGH. The model conflated a manoeuvre with the impulses that perform it, in two places | Numbered. It published a total two-impulse Hohmann budget as an "equivalent altitude step" and read it in prose as one burn, and it counted repositioning legs as ignitions. Corrected by vis-viva, a bisected Hohmann inverse, and an explicit ignition schema. The second surface reverses a published conclusion: Case B needs 7 post-primary ignitions against an assumed budget of 4, not 3 |
| Pacing | The one-orbit-per-leg case was called "the real pace" | Withdrawn. One orbital period per leg is an illustrative scheduling case, not a lower bound: a Hohmann transfer reaches the opposite apsis in about half an orbit. Three pacing cases are now shown, the 47 minute transfer arc is separated out as the only physical duration, and the conclusion that "time is the binding constraint" is replaced by a statement conditioned on the scenario |
| Batching | A fixed-dv-per-reposition table was presented as evidence that batching wins | Withdrawn. The rows do not deliver the same mission, which the code's own docstring conceded while the prose drew the conclusion anyway. Renamed reposition-count scaling, bounded to what it shows, and a fair equal-mission batching trade is left explicitly open under P113 |
| Thrust | A 15 to 30 kN sensitivity was declared in the ledger and never swept | Swept. At 15, 20 and 30 kN the 2 s floor on the reference stage is 30.2, 40.3 and 60.6 m/s, so the coarse-actuator conclusion survives the whole declared range. The ledger gains a "Swept?" column, so an unswept sensitivity is now visible rather than implicit |
| Gate | `--check-doc` checked presence, not agreement | It asked whether each formatted number appeared anywhere in the document, so a correct value beside a wrong label passed. Sixteen tables are now generated between markers and compared as exact text. Nine faults were injected to demonstrate it fails on each, including the two the old gate could not see |
| CI | The `gates` workflow had never once run | Every run since 2026-08-22 ended in `startup_failure` with zero jobs. The cause is not the file: this repository's Actions settings do not permit third-party actions, so any workflow referencing `actions/checkout` is refused before dispatch. Demonstrated by running five workflows on one branch, four with `actions/checkout@v4` and one with no action at all; only the last started. `gates.yml` now fetches with git and uses the runner's own Python, and the reason is written into the file so nobody reinstates a `uses:` line |
| Sources | The evidence table cited "company material" rather than documents | Eight sources now carry title and URL, the taxonomy separates company-issued text relayed by a wire from trade reporting, and every row records how it was retrieved. No row is COMPANY_PRIMARY: the hosts return a policy denial to the network this study runs on, so nothing was read on the company's own property, and the table says so |
| Evidence | "Semi-cryogenic" was used to establish the propellant pair | It cannot. Semi-cryogenic is an architecture family. The propellant row is now owned by the turbopump design publication, which names LOX and kerosene, and the semi-cryogenic row is context only |
| Heading | The section title and diagram implied established engine restart | Retitled to name the stage as assumed, and the diagram step reads MAIN-ENGINE RESTART, ASSUMED. Whole-engine restart is not publicly established for this case and the file must not be quotable as saying it is |
| README | The front page said the host repositions "on its own reaction control" | Too specific, and it contradicted the Class A/B/C architecture. A host may use main propulsion, auxiliary propulsion, reaction control, some combination, or none. Now reads "whatever planned post-primary propulsion authority the host makes available" |
| Freshness | The results-freshness gate compared floating-point JSON byte-for-byte, which no two machines can satisfy | Found the moment CI first ran: `run_a69.py` and `run_a70.py` reproduce byte-identically here and not on a GitHub runner, because both solve eigenvalue and linear systems through numpy and the last bits depend on the BLAS the interpreter was built against. The gate had only ever executed on one machine, so an unachievable claim had gone unnoticed. Values are now compared at 1e-9 relative with everything non-numeric still compared exactly. Not a weakening: P110's staleness was a factor of 15.6, and the new comparison was shown to catch a 2-parts-in-1e9 drift, a flipped band verdict, a 1 % list element, a changed string and a removed key, while tolerating one part in 1e16 |
| A70 | The admissibility sagittas carry about 1e-4 of numerical noise, by construction | Measured when the first tolerance was still too tight to pass on a runner. A69's centreline reproduces to 3e-9, ordinary BLAS sensitivity in a linear solve. A70's sagittas reproduce only to 1.3e-4, and the reason is cancellation: a three-point sagitta subtracts nearly equal ordinates, about 1.627 mm at the 40 mm land, to leave 0.049 um, amplifying relative error by roughly 33,000. 3e-9 times that is 1e-4, which is what is observed. The figure is conditioned badly by construction rather than computed badly, and nothing physical moves: 0.43398 um against 0.43404 um on a 25 um radial clearance, where A70's conclusions are factors of two. Tolerances are now per file with the reason beside each, and the gate still catches staleness by three orders of magnitude. Embedded numbers inside run-sheet detail strings are compared numerically too, so a moved value is tolerated while a changed verdict word is not |
| P113 | Re-audited, scope confirmed | Stays `PROGRAMME` and `COMPUTATION`. The corrected model widened what closing it requires, because it shows ignition count, shell choice and release velocity to be coupled. It is not moved to `historical study`, not closed by this study, and not used to lower any historical study requirement |

---

## 2026-08-20 (fifty-third pass): the visuals reach the front pages, and A35 turns out to be stale

| ID | Item | Detail |
|---|---|---|
| P95 | CRITICAL. A35's headline figure is pre-A46, and correcting it reverses A35's own escape route | Found while drawing the ledger for the front page: the figure would not agree with the text, and the figure was right. `constraint_ledger.json` was regenerated on 2026-08-16 in the *"Apply A46"* commit; the run sheet was last touched on the 14th. 49.23 kg / 58.2 % to 88.67 kg / 70.06 %, and per satellite 4.10 to 7.39 kg. *A35's one route out of kill criterion 1, "at twenty-four satellites the same 49.23 kg is 2.05 kg each, and the criterion closes", is 3.69 kg each and does not close.* Propagated to seven documents; A35 annotated with a dated block, no band re-declared. |
| A2/A3 | The field map, drawn for the first time | `analysis/make_field_map.py`, from `field_3d.halbach_pair()`, extracted from `kt_depth_resolved` so the picture and the thrust integral build the same geometry. Kt verified unchanged at 10.5386. Centre-plane 0.5041 T against a depth mean of 0.4759 T, the assumption A2 corrected. |
| A35 | The ledger, drawn | `analysis/make_ledger_figure.py`. Three of the six requirements carry no mass on their own; no corner of the 64 reaches the criterion. |
| Blender | An exploded view, and the renderer learned to do them | `build_scene()` now accepts `(name, (dx,dy,dz))` as well as a bare name, so every view written before exploded views existed behaves identically. Two framings were discarded before one read as a stack rather than scattered parts. |
| Front pages | Four pages had no images at all | `VOLLEY-lab` contained no image file of any kind; the paper and thesis each had 17 figures in their own directory and referenced none. All four now lead with something, by `raw.githubusercontent.com` URL where the repo holds no binaries, one copy of each render in the programme. Every raw URL verified against a file already pushed. |
| VOLLEY | README Results and the Pages site | Both gain the flow field, the field map, the exploded stack and the ledger. Captions carry the caveats: the CFD pressure term is solved, the viscous term is bounded and not. |

---

## 2026-08-20 (fifty-second pass): a provenance audit of every constant

| ID | Item | Detail |
|---|---|---|
| P94 | A13 band 5 passes on a host control authority E5 says does not exist | `RCS_TORQUE = 0.1` sat in `attitude_budget.py` with no units, no comment and no source, and A13 band 5 passes on it: *"settling below 0.01 °/s with a 0.1 N·m RCS authority."* `EXTERNAL_EVIDENCE.md` records E5 as "no host propellant or control authority figure exists." *The project recorded that it had no such figure and used one to pass a band.* Labelled a declared assumption in script and run sheet, cross-linked to E5, verdict annotated rather than re-declared. No source was invented. |
| A13 | The deployer inertia was 40 % low, and correcting it improved the result | `M_DEPLOYER` was the literal 124.5 kg, `mass_properties`' loaded figure *before* A46. `deployer_inertia()` is added to the host's, so the rotating body is the loaded deployer: 174.6 kg, now read live from the results file. At 500 kg host: inertia 329.7 to 345.0 kg·m², return peak 0.13625 to 0.13021 °/s, offset 0.42074 to 0.40209 °. At 200 kg the return peak falls 0.44323 to 0.38512. Rows 3 and 4 still FAIL, *a correction that improves numbers is reported like one that damages them.* Propagated to both manuscripts and both PDFs rebuilt. |
| P93 | A fifth instance, inside the script that computes the right answer | `mass_properties.py`'s docstring still read 76.5 / 124.5 / 0.44. Its own JSON says 126.6 / 174.6 / 0.46. Six lines below sits the line *"A docstring is the first thing anyone reads about a script, so it is worth as much as the code under it."* Corrected, with the A46 history recorded in the style the docstring already used. |
| Audit | 126 scalar constants scanned; 14 labelled | Every module-level scalar in all 68 analysis scripts, excluding universal constants and sweep ranges. The declaration discipline held: A46's seven assumed enclosure inputs, driving the 50.04 kg that is 58.6 % of the stage credit, are all declared, and its band 7 says *"zero undeclared."* `RCS_TORQUE` was the only genuine contradiction in 126. `BEARING_KG`, `CONVERTER_KG_PER_KW`, `Q_DESIGN`, `MOS_TARGET`, `M_DIST`, `ECC`, `M_STOWED`, `SIGMA`, `TAU`, `MAG_FULL_SCALE`, `SEAL_CP` and `ASSUMED_ARM` now name themselves as declared assumptions beside the code. The remaining 112 are design choices and named cross-run imports, not unsourced claims. |
| Satellites | Clean | `pulsed-linear-motor-design-lab`, `orbital-deployment-trade-study` and `engineering-evidence-toolkit` carry no superseded VOLLEY figures outside their `reference/` copies. The only hits are unit-test fixtures passing `16.388` as a function argument, inputs under test, not claims. |
| Scope | This audited code, not prose | A full trace of every asserted number in `docs/` back to a results file is a larger job. P93 is the proof it is needed, and `tools/check_paper.py` is the right shape for it. |

---

## 2026-08-20 (fifty-first pass): Gen5 closes

| ID | Item | Detail |
|---|---|---|
| P93 | CLOSED, and the entry was wrong about its own cost | It called for a re-run. `payload_family.py` already read `dry_kg` live and `payload_family.json` already carried 126.6 with all nine rows. *The analysis was current the whole time; only the manuscript was stale.* |
| P93 | Fixing it exposed two things the audit had missed | A third stale mass in the mechanical section (84.5 / 132.5 / CoG 0.44 m to 126.6 / 174.6 / 0.46), and the family table stale in every column, its velocities were at the pre-ADR-030 point, so the 3U row read 16.4 m/s at 10.5 g against the paper's own rated 16.0 at 10.1 two paragraphs earlier. The table contradicted its own paper, and seven rows were 76.5-based while the 3U row alone was 84.5-based. |
| Family table | Regenerated from `payload_family.json` | All eight rows, all five columns. 3U is 10.550 kg/satellite. The *"factor of thirty across the family"* claim, invariant in dry mass, therefore always checkable, is 109x. |
| A29 | The flow field, at last | `validation/cfd/fields.py` parses the committed case in pure Python, `postProcess` aborts in this OpenFOAM 1912 build with an IOstream error, the same class of failure A29 recorded for `wallShearStress`. 721 781 points, 1 884 060 faces, 581 779 cells. The mid-plane slice shows stagnation at the nose, separation at the shoulders and a wake unrecovered by x = 2.2 m, A29's "classic bluff-body split", visible for the first time. |
| Figures | `A29_cfd_report.png` was an orphan in both manuscripts | Present in `figures/` since it was generated and referenced by neither `paper.tex`. The paper had never once shown its CFD work. Rescued, and the new wake figure placed beside it. Unreferenced-figure count in both repos is now zero. |
| Captions | Both CFD captions state the bound | The pressure term is integrated from the solved field; the viscous term is not solved and is bounded by a flat-plate correlation. *A picture of a result must not imply more than the result claims.* |

---

## 2026-08-20 (fiftieth pass): Gen5 closes, and the paper does not

| ID | Item | Detail |
|---|---|---|
| P93 | CRITICAL. The paper's system mass is 50 % low, in its own abstract | `mass_properties.py` and `BASELINE.md` give 126.6 kg dry; `paper.tex` says 84.5 kg in the abstract and conclusion and 76.5 kg in the payload-family table caption. The arithmetic names the cause: A46 itemised the enclosure on 2026-08-16, an 8.00 kg placeholder becoming 50.04 kg, and 84.5 − 8.00 + 50.04 = 126.54; 84.5 − 8.00 = 76.5 is the caption. Both figures are pre-A46 and the paper was built three days after it landed. It is a re-run, not a patch, the caption states per-satellite mass *uses* 76.5 kg, so every row of that table moves by 65 %. Nothing compares the paper against `BASELINE.md`: P84's shape, one deliverable further out. |
| A7 | Superseded, and the closure document said otherwise | A7 was specified and correctly never run, Chrono unavailable, and the release mechanism it would simulate is undefined. A7-R gave the budget (1.465 mN·m·s), A23 modelled three rigid-body stages with mechanism properties as swept axes (ideal release 0 °/s, skew tolerance 50.6 µs, cradle reaction 85.0 N against 200 N), A34 closed the impact five of five (settles in 27.25 ms of a 146.4 ms stroke, exactly zero residual rate). `PHASE_I_CLOSURE.md` listed A7 as unrun Category A work until today, ten days after A23 answered it, *a stale gap inside the closure document itself.* |
| GEN5_CLOSURE | New: `docs/GEN5_CLOSURE.md` | The whole Phase I case on one page, what Gen5 is, every headline number against its source, what was cross-checked and by what tool, what failed, the seven kill criteria with three crossed and unmoved, the permanent caveats (E4, A9 re-tested at 403 today, T-1...T-8, B-1...B-4), and the handoff to hardware. It states that all four specified benchtop tests validate subsystems ADR-032 deleted, so the benchtop programme is Gen5's closure rather than historical study's start. |
| P16 | README's description was stale, not the paper | `paper.tex` withdrew the invariance claim in the abstract, §V-B, the sensitivity and limitations sections, and the built PDF carries it. The README said the opposite. *The source was fixed and the summary was not.* What remains open is the replacement claim, which needs A9, still 403 at CONNECT, re-tested. |
| Paper / thesis | historical study added as future work; both PDFs rebuilt from source | A bounded section: the architecture change, what it deletes, that nothing in it is measured, that its trim stage is suspended, and that it is reported in the repository rather than the paper *for the same reason the 3-D field correction is computed and deliberately not applied.* Both PDFs now demonstrably rebuild, the check that would have caught the stale P16 description. |
| CFD | Flow-field visualisation not produced, and why | The converged fine free-stream case is committed and reconstructed at t = 1800. `postProcess` aborts in this OpenFOAM 1912 build with an IOstream error, the same class of failure A29 already documented for `wallShearStress`. Not forced, and recorded rather than worked around. |

---

## 2026-08-20 (forty-ninth pass): the stage credit at the store that was actually sized

| ID | Item | Detail |
|---|---|---|
| A45-R2 | The stage credit re-run at A56's store, four of eight, all five predictions held | A45 and A45-R both read the store as A43's 5.38 kg. A56 sized it at ADR-034's charge pressure and got 3.1216, 42 % lighter, and nothing depending on it had been re-run. The allowance moves for the first time: A45-R's finding was *"the allowance never moved, the credit did"*, and sizing the store takes it 7.17 to 9.43 kg, break-even 8.4 % to 11.0 %. |
| P68 | Still CRITICAL | Full credit 1.4027 to 1.2145 kg/satellite, hostile 3.2709 to 3.0827. ADR-032's falsifier fires by a third less and still fires, at 11.0 % against a declared 30 %. *A CRITICAL entry improving is not a CRITICAL entry resolved.* The 16.5 % the entry quotes is against the 43.33 kg credit A46 replaced, a break-even percentage means nothing without the credit it is a fraction of. |
| MASS-01 | The project was publishing three figures for one quantity | 1.403 (A45/A45-R/P68, at 5.38 kg), 1.296 (README, index.html, GENERATIONS, at ADR-034's scaled 4.10 kg) and 1.324 (historical study.md, same store *plus* the trim stage). None was wrong for its own scope and no page said which scope it was using, the front page's hostile 3.164 is the 4.10 row while P68's 3.108 is A45's at 5.38. A45-R2 band 8 reconciles all five readings and names 1.2145 kg/satellite canonical: A56's sized store, without the trim stage, because ADR-036 suspended it. Any page quoting 1.3173 must say it includes a section that may not be built. |
| A45 / A45-R | Frozen against drift | `stage_credit.py` gains `STORE_KG_A43 = 5.38` and reads the live store from `cad/parameters.json`; `main()` raises if the A43 helper stops reproducing. Band 1 re-evaluates the whole model at the frozen store and must return 85.36 / 1.403 / 3.271. *A44 and A48 drifted silently because nothing did this.* |
| Propagation | Six documents | `README.md` (twice), `docs/index.html`, `docs/GENERATIONS.md`, `docs/generations/LEGACY_STUDY.md`, `docs/KILL_CRITERIA.md`, `docs/LEGACY_STUDY_CLOSURE.md`, and a dated block on ADR-032's falsifier 1. ADR-034's own table keeps 1.296, it is that decision's record of what it decided. |

---

## 2026-08-20 (forty-eighth pass): the seal is specified, and the trim stage stops

| ID | Item | Detail |
|---|---|---|
| ADR-036 | The seal is specified at 17.8 N and the trim stage is suspended | No new analysis. [A61](validation/A61_seal_class.md) band 3 had already run it: a seal meeting its own thermal requirement, 4.00 %, set by A58 band 5, is tighter than the 5.00 % at which the trim stage stops earning its mass, so one strictly implies the other. The stage is not deleted: deleting on a specification would repeat ADR-033's own error of adopting before the falsifier was answered. Work stops until P67. |
| P89 | Closed | `cad/parameters.json` gains a `LEGACY_STUDY_seal` group carrying both numbers and saying which is which, `friction_max_N` 17.8 as the specification, `friction_allowance_N` 83.40371375447981 as A41's retained ceiling, 4.68x apart, plus `measured: NO`. |
| P84 | Two dated scripts frozen at their own design points | `LEGACY_STUDY_dispersion.py` gains `STROKE_A44 = 2.18` and `trim_stage.py` `STROKE_A48 = 2.18`, the pattern `precharged.py` already used for `STROKE_A41` and that had not been applied here. A44 was computing a shot at 50 bar over 8.0 m, a point never adopted, and returning 1.504 % against its published 1.113 %. A48 band 3 was reporting 0.497 % where A48 declared 1.822 %. Both reproduce exactly again. |
| P84 | Its own closing sentence corrected | It claimed historical study's dispersion at ADR-034's point *"is not known"*. It was known: A55 computed 3.9798 % on 2026-08-19 and A61 reproduced it. *The defect was never a missing number, it was that the number never propagated.* |
| DISP-01 | 3.9798 % propagated into four documents | `ADR-033`, `docs/GENERATIONS.md`, `docs/BUILD_READINESS.md` and `docs/generations/LEGACY_STUDY.md` all carried A44's 1.113 % as historical study's figure, 3.6x low. Every surviving instance is now explicitly attributed to A44's 2.18 m machine. Friction's variance share rises with it, 93.4 % to 98.68 %. |
| P92 | Deferred, not dropped | A66 is not written: computing how well a stator couples through a conducting tube is only worth doing for a stator that will exist. Stays LIVE. If P67 measures above 22.3 N, it becomes the next run with nothing in front of it. |
| P67 | Now decides an architecture | It has a threshold in the unit seal data is quoted in: <= 17.8 N closes P88 and retires the stage; > 22.3 N fires ADR-036 falsifier 1 and ADR-033 stands. |
| CAD-07 | `unit_for()` asserted "mm" for every physical quantity historical study added | Not numbered, a `tools/` defect under ADR-021. `cad/DIMENSIONS.md` rendered 200 bar as "200.0 mm", a 473 K ceiling as "473.0 mm", a 3.1216 kg store as "3.1216 mm", and `first_fill_s` as dimensionless because "fill" appears in the name. The suffix table now covers kg, bar, K, J, W, A, Hz, L, s, m/s, m², m³, kg/m³ and N/kA·m, with a containment pass for qualified names like `exit_velocity_m_s_zero_friction`. Geometry keys are unchanged. *This is the document whose stated purpose is to be read instead of the JSON by whoever is cutting metal.* |

---

## 2026-08-19 (forty-sixth pass): the stroke becomes the stage

| ID | Item | Detail |
|---|---|---|
| A49 | The velocity, acceleration and stroke surface, seven of nine bands | 14 of 63 points beat the adopted historical study on exit velocity, peak acceleration and gas per shot at once. All fourteen sit at L = 8.0 m, A37's whole usable acceleration length. Band 3 confirmed peak acceleration is independent of stroke, `a_peak = p₀A/m` contains no *L*, so stroke is an exchange rate between charge pressure and velocity, not a performance knob. |
| ADR-034 | Adopted: 8.0 m of stroke at 22.73 bar | Exit velocity held at 29.009 m/s (34.280 zero-friction), peak acceleration 25.00 to 11.36 g, gas per shot 112.3 to 51.0 g. Both falls are 54.55 %, from the same charge-pressure change. Added mass per satellite 1.403 to 1.296 kg. |
| P78 | A49 band 6 failed, and it is the finding rather than the failure | Friction scales linearly with contact length while shot work saturates, so friction's share rises across the sweep: 9.75 % to 12.90 % at fixed pressure, and 28.39 % at the adopted point. The gap between the two velocity numerators widens from 5.00 % to 15.38 %. P67 now governs the design point rather than a correction to it. |
| VEL-01 | The velocity increase was available and was not taken | The Pareto front carries 30.97 m/s at 12.5 g, dominating on all three axes and 6.8 % faster. Taking it would invalidate A15, A20, A44, A50 and A52 at once, none of which has been re-run. A number moves when its consequences have been run. The follow-on is named in ADR-034. |
| P82 | The reservoir is still sized for 50 bar refills | 9.55 L at 200 bar, from A43's thermal argument at the old charge pressure. The ~ 4.10 kg store ADR-034 quotes is A49's gas-ratio scaling, not a sized store, and the reservoir saving is the whole of the mass argument, the tube itself gains 0.829 kg. |
| P83 | The trim stage's authority was sized at a friction share that has tripled | A48 sized ±0.323 m/s against A44's dispersion at 9.75 % friction; the adopted point runs at 28.39 %. Neither A44 nor A48 has been re-run. HIGH, because a larger authority makes ADR-033's unweighed pulse store, the project's most likely falsifier, more likely. |
| P81 | And the backup ejector got 3.67x worse | Clearing the sealed tube cost 181.8 J at 2.18 m against a 4.5 J ejector. At 8.0 m it is 667.2 J, a 148x shortfall. A53's masses are the 2.18 m case and are no longer governing. |
| CAD-G6R | historical study regenerated and re-rendered at the new geometry | Drive tube, stage rail and trim stator rebuilt; six geometry checks read back against `parameters.json` and pass. The renders were reframed, the assembly is 8.2 m at roughly 42:1, and the old camera distances put it off both edges. |
| CHECK-04 | A magic number in the geometry check, found by moving the design point | `build_legacy_study.py` compared the constant-pressure velocity bound against a bare 32.7, correct at 2.18 m and 50 bar and silently wrong anywhere else. It now reads the parameter it is derived from. |
| INDEX-01 | The run-sheet index was eleven runs out of date | `validation/README.md` stopped at A42. A43 through A53 are now indexed with their verdicts. |
| CLOSURE-01 | `docs/LEGACY_STUDY_CLOSURE.md` rewritten against what actually ran | Its Category A listed a provisional A49, A55 made before the design surface existed. Five of those runs happened under different numbers and one was not on the list at all. Remaining work renumbered A54, A60, with the structural case for an 8 m tube at 1 mm wall promoted to fourth. |

What authorised it. A49's bands were declared before `analysis/design_surface.py` existed.
No band was edited after a run, the two that failed are recorded as a declaration error and as
P78, and the design point moved rather than the band. All four checks pass.

> This file skipped five days, and the gap is stated rather than backfilled. The pass below is
> dated 2026-08-14. A43 through A48, ADR-033 and A50 through A53 all happened between then and
> this entry and were never logged here. Each is recorded in its own run sheet, in
> `OPEN_PROBLEMS.md` and in `validation/README.md`; this log is the thing that fell behind, and
> writing the missing passes now, from memory of what the other files already say, would be a
> reconstruction rather than a record. It is left as a gap.

---

## 2026-08-14 (forty-fifth pass): historical study exists as geometry

| ID | Item | Detail |
|---|---|---|
| CAD-G6 | `cad/build_legacy_study.py`, generated from the same `parameters.json` | Six parts, byte-stable across rebuilds, and every dimension is a run result rather than a choice: bore and stroke from A39, chamber from A41, reservoir from A42, cradle preload from A38. Six geometry checks read back against the parameter file and pass. |
| PARAM-01 | `LEGACY_STUDY_drive` and `LEGACY_STUDY_store` added to the parameter file | The single source of truth now carries both generations. Gen5 regenerates byte-identically against the extended file, which is what a generated model is for. |
| INHERIT-01 | One part of six is inherited, and it is the right one | The magazine cassette. A36 and A37 agree from opposite directions that the containment is the only subsystem surviving every architecture deletion, 11.45 kg of it. |
| HONEST-03 | Three things it draws that are not settled, in the script's own header | The reservoir carries 11.25 L, the adiabatic end of P64, when the isothermal figure at this cadence is 7.65. The cradle is an envelope, not a design, A34 says the mechanism does not exist and A38 raised its preload to 201.7 N against a <= 1 N release residual. And the stage rail is a straight extrusion of unknown provenance, because no provider has agreed to anything and A37's 43.33 kg stage credit is the least-examined number in the architecture. |
| GUARD-01 | `check_artifacts.py` guards historical study against its sources | One STEP guards the set: they are written in a single pass or not at all, the same rule Gen5 uses. |
| CHECK-01 | And the guard produced a false positive on Gen5, which is a defect in the guard | Adding `LEGACY_STUDY_drive` and `LEGACY_STUDY_store` to `parameters.json` made Gen5's STEP *older than its source* by commit time, while it regenerates byte-identically. Commit time is a lossy proxy for currency: a source can change in a way an artifact does not depend on. |
| CHECK-02 | Fixed by proving currency rather than inferring it | A pair may now name a regenerator. One that looks stale by time is rebuilt and compared; if nothing changes it was current and the timestamp was lying. Pairs with no regenerator keep the time comparison. |
| CHECK-03 | It also caught a true positive on the same run | `cad/BUILD.json` really was stale, its recorded `parameters.json` hash, and `DIMENSIONS.md` missing both new groups. The check was right once and wrong once, in the same pass, which is the argument for the fix rather than against the check. |

What authorised it. A41 and A42 fixing the last free dimensions. No band was edited, no
analysis was re-run to suit the geometry, and the geometry check reads the parameter file rather
than restating it. All four checks pass.

---

## 2026-08-14 (forty-fourth pass): filling is not the constraint, and the bottle cannot give its gas back

| ID | Item | Detail |
|---|---|---|
| A42 | Five of six bands. ADR-032's replacement falsifier is answered | *Can a 2 L chamber be filled to 50 bar inside the inter-shot window?* Yes, 4.14 s through a 1 mm orifice, against the 4 s index plus 6 s return already in the cadence. Filling is not the constraint. |
| P64 | A41's reservoir is sized on gas the bottle cannot give back | A41 divided total charge by storage pressure, which assumes the bottle can be drawn to zero. Below the charge pressure it cannot fill a 50 bar chamber. A42 measures it running out at shot seven of twelve. |
| BOUND-01 | The correction is bounded, not single-valued, and the reason is A42's own model | It treats the reservoir as adiabatic, so it cools as it empties, right for a fast blowdown, wrong for a twenty-minute cadence where the bottle re-equilibrates. Isothermal 7.65 L / 4.67 kg; adiabatic 11.25 L / 6.01 kg. Band 3 fails at either end and bands 5 and 6 pass at either end, so the architecture is not in doubt, the store mass is, by about 1.3 kg. |
| MASS-03 | Added mass per satellite, corrected | 1.344 to 1.455 kg against an unmoved 2.0 kg threshold, from A41's optimistic 1.343. Dry mass per satellite still crosses at 7.042 and both are still reported together. |
| PRED-03 | The first prediction this session that held | Declared before the run: *band 3 fails, everything else passes, fill is roughly 4 s at 1 mm, the correction is 6 L to 8 L.* Fill was 4.14 s, band 3 failed alone, and the isothermal correction is 7.65 L. It is also the first that was checked with a calculation before being written down, three of the four wrong ones were intuitions. |
| REPAIR-02 | And the cheap repair is already visible | The fired chamber vents 43 bar of a 2 L volume every shot and nothing models recovering it. That is where the reservoir shrinks if it ever needs to. |

What authorised it. ADR-032's own replacement falsifier, and a second question found while
scoping it. No band was edited, widened or moved; A42's six were committed before
`analysis/fill_window.py` existed, and band 3 was deliberately declared at A41's 6 L rather than
at the 8 L the scoping arithmetic gave, because a band restated to match a number already
computed tests nothing. All four checks pass.

---

## 2026-08-14 (forty-third pass): the store is specified, and three predictions in a row were wrong

| ID | Item | Detail |
|---|---|---|
| A41 | Eight of eight bands. historical study's energy store is specified | A 2 litre chamber at 50 bar, charged over the sixty seconds already spent indexing and fired as a closed adiabatic expansion. 30.54 m/s at 25 g on a 4.66 kg store. |
| P63 | Closed by deleting the component rather than pricing it | A40 showed the fixed orifice fails and A39's 2.98 kg assumed an unnamed regulator. There is no regulator. A pre-charged chamber has no flow-rate problem by construction. |
| MASS-02 | Added mass per satellite improves while velocity rises | 1.343 kg against A37's 1.608, at 30.54 m/s against 27.1, because A37's selected point was the large stage class and this needs only 2.18 m of stroke. Threshold unmoved at 2.0 kg; dry mass per satellite still crosses at 7.042. |
| PRECISION-01 | The precision argument finally lands on a mechanism | Charge pressure gives 0.499 % of velocity per 1 %, and it is a static measurement taken before the shot. A40 measured valve timing at 10.53 % per ms. Commanding on the charge stroke is ~21x more precise than commanding during it. |
| RATIO-01 | The expansion ratio is the binding variable, not the pressure | Velocity saturates toward a 2139 J constant-pressure ceiling, exactly A39's assumption, while gas grows linearly with chamber volume. 2 L to 4 L buys 1.0 m/s and costs 3.2 kg. |
| PRED-02 | Three predictions, three wrong, on a run where every band passed | The seal was predicted to bite: tolerance is 0.83 mbar·L/s against static seals at 10⁻⁶, wrong by four orders. Refined to friction: tolerance 83.4 N, wrong by 4x. Then the gas budget: 4.66 kg against a 12.55 budget, wrong by 2.7x. The first two were caught and corrected before declaring; the third was declared in confidence and failed. |
| HONEST-02 | And that is the pattern, stated rather than buried | Every intuition about what would bite has been wrong since A35, and every band has caught it. It is an argument for declaring bands, not for trusting the person declaring them. |
| ADR-02 | ADR-032's second falsifier retired and replaced with a narrower one | Not *"the regulator weighs more than the store"*, there is none. Now: *"a 2 L chamber cannot be filled to 50 bar inside the inter-shot window"*, which A41 did not check and A42 should ask first. |

What authorised it. P63, and A40's third named repair. No band was edited, widened or moved;
A41's eight were committed before `analysis/precharged.py` existed. All four checks pass.

---
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

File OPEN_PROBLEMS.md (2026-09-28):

# Open problems, known errors, and the fix list

Two categories: P-items are errors in the currently published paper and should be
fixed first. E-items are genuinely unsolved engineering.

> ## How to read the counts
>
> <!-- REGISTER_COUNTS:BEGIN -->
> 154 numbered entries, of which 51 are live. Every entry carries a
> `Status:` line written by `tools/register_status.py`. This block and the result JSON
> are generated from the same classifications.
>
> | Status | Count | Meaning |
> |---|---:|---|
> | `LIVE` | 51 (31 P, 20 E) | open engineering; something still has to be done |
> | `CORRECTED` | 60 | found, fixed and propagated, retained as the published record |
> | `CLOSED` | 43 | resolved, with the closer named in the entry |
> <!-- REGISTER_COUNTS:END -->
>
> Four of those moves are a classifier repair, not new engineering. `\bRESOLVED\b` matched
> inside *depth-resolved*, and the tool read its own `Status:` line back in on the next run, so a
> single wrong call re-justified itself forever. P18, P30 and P32 were sitting as `CLOSED` on the
> strength of a hyphenated adjective; P43 was sitting as `CLOSED` on the same latch. The
> conservative direction is `LIVE`, and the repair moved three entries into it.
>
> These counts were stale by four entries until 2026-08-10, under a sentence claiming they
> "cannot drift apart again". They could: `register_status.py --check` validates each entry's
> own `Status:` line, and never read this table. The claim has been removed rather than repaired,
> because the table is still hand-copied from the tool's output and a promise the checks do not
> enforce is worth less than none. Run `python3 tools/register_status.py` and compare before
> quoting these numbers anywhere.
>
> Update 2026-09-06. The current count block above is now generated and checked alongside the
> result JSON. The earlier failure and classifier history remain below it. No entry changed
> disposition in this repair.
>
> This distinction did not exist until 2026-08-06 and its absence was itself a defect: a
> reader could not separate live engineering debt from published history, so "37 defects" counted
> both. `docs/PHASE_I_CLOSURE.md` §0 named fixing it as the first act of closing Phase I.
>
> The statuses are classified from each entry's own text. A handful sit close to the boundary
> between `LIVE` and `CORRECTED`, where the defect is fixed but a consequence remains, and are
> marked `LIVE`, which is the conservative direction.

> ## FROZEN 2026-08-10, [ADR-021](docs/adr/021-freeze-the-register.md)
>
> This register is closed to new entries except in three cases. It remains authoritative and
> nothing in it has been deleted, closed or downgraded, all 81 entries stand, and the 38 live
> ones still carry their named next steps. A freeze is not a purge.
>
> A new numbered entry may be opened only for:
>
> 1. a defect in the machine, an error in the design or a model of it that changes what the
>    hardware would do;
> 2. a defect that makes a published Phase I deliverable wrong, the paper, `BASELINE.md`,
>    the portfolio. This is the P38 case and it stays numbered;
> 3. a validation band miss. `validation/README.md`'s rule is untouched: a missed band
>    produces a numbered defect, never a widened band.
>
> Everything else is fixed in place with a `CHANGELOG.md` line and no number, defects in
> `tools/`, bookkeeping drift, stale cross-references, and observations about this file.
> P39 would not be numbered under this rule. It keeps its number because the freeze is not
> retroactive and this project does not rewrite its record.
>
> Why. The discipline caught a separation figure wrong by 5.7x, a force 37 % high, a claim in
> the paper's own abstract, and P38. It also grew to ~16,000 lines of prose around ~3,200 lines of
> analysis, and began producing its own defects: of the three entries opened on 2026-08-10, one
> was in the paper and one was in the export tool's file-copying semantics. Meanwhile B-1, the
> first measured number in this project, ~₹22,000, bill of materials already written, has never
> been ordered. ADR-021 has the full argument and states what the freeze risks.
>
> The band rule is not affected, and neither is Phase II: `VOLLEY-lab`'s register is not
> frozen. Reviewed at the next baseline boundary.

Last reviewed 2026-08-10.

---

## Lethality ranking, confirmed 2026-08-10

Ordered by how likely each live entry is to be design-fatal, not by ID, date, or the
HIGH/MEDIUM/LOW severity already carried in each entry. Those severities rank *how wrong a
published number is*; this ranks *how likely the machine is not worth building*. The two orders
are different, and neither replaces the other.

Nothing below is deleted, renumbered, or reworded. This section only orders what already
exists, and the entries it points at remain the authority on their own content.

Confirmed by the author on 2026-08-10, including the two places where it disagrees with the
register's own severity labels.

### The five most likely to be design-fatal

| # | Entry | The failure it would cause | What would settle it either way |
|---|---|---|---|
| 1 | E30 | Below r = 0.99326 per element per cycle, the machine delivers less total mission value than a spring dispenser, nine of thirteen elements forfeit the remaining manifest where a spring forfeits one satellite. The product then has no reason to exist | Cycle-life test of the escapement, retention gate and sled to twelve cycles with margin, giving a measured per-element reliability. This is metal, not computation |
| 2 | E4 | Every number in the repository descends from a field model checked only analytic-against-analytic. If the measured thrust constant departs materially from 11.03 N per kA/m, the design point, the velocity, the lifetime multiplier and the comparison against a spring all move together | B-1, a gaussmeter and eight magnetised blocks, ₹22,000, method and bill of materials already written in `docs/B1_ORDER.md`. Unordered |
| 3 | E33 | The residual dipole from magnet tolerance saturates a 15 N·m·s wheel in 3.0-7.5 days with the machine idle. Combined with E31, a host that has lost attitude authority may not legally deploy, so the campaign ends before the manifest does | Measure the moment and axis of each block on receipt and compute the assembled residual, rather than assuming the Monte-Carlo tolerance distribution. The same instrument B-1 buys |
| 4 | E34 | The modelled 200 g arrest puts 18.5 kN through the structure while other satellites are stowed. The project's 25 g study ceiling is not a CubeSat qualification. If the payload-specific shock case does not close, arrest loads or geometry must change; the modelled 50 g case needs another 202 mm of run-out | A shock response spectrum and force-time history at the cassette interface, compared with a named payload's qualified levels and provider interface |
| 5 | E35 | The payload sits 20 mm from the array at 442x a magnetometer's full scale, and soft-magnetic parts leave permanently magnetised. The claim that the satellite is never modified is therefore false as built, and that claim is the product | Carry a longitudinal-separation layout into `cad/parameters.json` and recompute the field at the real payload station, or write a magnetic-cleanliness limit into a payload interface document. Computation, not test |

### Where the rest sit

Serious but not fatal, each has a known fix and the fix is affordable. P46 (K_t is
4.42 % high) moves the design point but not the architecture; P28, P36, P37, P41
and P32 are design or analysis work with no result yet suggesting the machine cannot be
built; E29 and E31 compound E33 rather than standing alone; E32 reduces to a written
inhibit.

Bounded scope rather than viability. E9, P44 and E28 narrow what the machine can
serve without threatening whether it works at all.

Bookkeeping, provenance and hygiene. P10, P14, P19, P20, P33, P35,
P38, P39, E16, E18 and E25 are records that disagree with each other or with
their sources. They matter for whether the repository can be trusted; none of them is a reason
the hardware would fail.

Not engineering. E14 and E15 are disclosure and funding.

### The disagreement this ranking has with the register's own severities

E4 carries no severity label at all and is ranked second here. P34 is labelled HIGH and
does not appear in the top five, because a magnetometer-carrying payload being excluded bounds
the market rather than the machine, and E35 may remove the constraint entirely. P45 is
labelled LOW and is genuinely low. Confirmed as written. If it is revised later, the entries themselves are unchanged and this
section is the only thing that needs editing.

---

## P: Errors found while building this repo (paper does not match its own scripts)

> STATUS (2026-07-23): P1, P4 all RESOLVED in `paper/paper.tex`. Fixes, causes and
> before/after values are logged in `CHANGELOG.md` (entries P2-01, P2-04). The items are
> kept in full below for the audit record. Two related defects found in the process were
> also fixed: the F06 conjunction figure was regenerated at the rated velocity, and a
> stale `astro.py` docstring value was corrected, both logged in `CHANGELOG.md`.

### P1. Conjunction minimum is wrong AND not a robust quantity: HIGH PRIORITY
> **Status:** `CLOSED` — resolved; see the entry for what closed it

RESOLVED 2026-07-23, see CHANGELOG.md P2-01.
The paper states a 30-day minimum satellite-to-stage approach of 45.3 km. That
figure was computed at 20.65 m/s, the superseded operating point. At the paper's
own rated velocity of 20.37 m/s, `analysis/astro.py` gives 4.6 km.

Worse, the quantity is fragile. Sweeping ejection velocity:

| Î"v (m/s) | min approach (km) |
|---|---|
| 20.00 | 37.5 |
| 20.37 (rated) | 4.6 |
| 20.50 | 56.1 |
| 20.65 (paper's value) | 45.3 |
| 21.00 | 63.4 |

This is a near-resonant beat sample, not a design property. A ±2.5 % velocity change
moves it by more than an order of magnitude.

Follow-up: `validation/A6_conjunction_cara.md` specifies the quantitative version,
probability of collision via NASA's CARA tools, which integrates over the covariance
instead of sampling one geometry. The test is whether Pc stays stable across the velocity
sweep that moves minimum distance by an order of magnitude.

> A6 ran 2026-07-31 in a reduced form and P1 stays open. Without GMAT, CARA or
> Space-Track there is no real covariance, so a 2-D Pc was computed against `astro.py`'s own
> propagator with an assumed one. The stability test came back void: at 14 to 63 km miss
> distances against a hundreds-of-metres covariance, Pc underflows double precision, and a
> spread of zeros is not a number.
>
> What the run found instead is better than what it was looking for. Pc has a maximum over
> covariance scale, a covariance wide enough to reach a 14.5 km miss is too diffuse to put
> probability inside a 5 m disc, and that maximum is 3.7e-8, some 2700x below the 1e-4
> anyone would act on, for any covariance whatsoever. So Pc is not *robust* where distance is
> fragile; it is irrelevant, bounded far below any action threshold.
>
> This does not close P1, because a bound is not a probability. It does say the paper's
> current position, the 9.9-day realignment period plus mandatory per-shot COLA, and no
> minimum-distance claim, is the right one, and is now supported rather than merely honest.

Fix: stop quoting a specific minimum distance as a safety result. Reframe around
what IS robust: the ~8.1-day phase realignment period, and the mitigation of disposing
of the host stage before the first realignment. State plainly that per-shot COLA is
mandatory because the approach geometry is sensitive to exact ejection velocity.

### P2. Peak current is stale: MEDIUM PRIORITY
> **Status:** `CLOSED` — resolved; see the entry for what closed it

RESOLVED 2026-07-23, see CHANGELOG.md P2-02.
Paper says 323 A. That belongs to the superseded 130 kA/m point. At the rated
140 kA/m, `motor_model.py` gives 392 A. Fix the paper, and check that the SiC
device derating discussion still holds at the higher current (it should, 96 V rail,
1200 V devices, but the current rating of the bridge and busbars needs restating).

### P3. Far-field stray values don't reproduce exactly: LOW PRIORITY
> **Status:** `CORRECTED` — found, fixed and propagated. Retained as the published record

> QUANTIFIED 2026-08-05 by `analysis/far_field_sensitivity.py`. P3's diagnosis was right and
> the size of it was not known. Sweeping `build_field(n_wave)` from 3 to 15 wavelengths against a
> converged reference:
>
> | Station | Deviation at the default n=7 (336 mm) | Converged |
> |---|---:|---:|
> | 10 mm | 0.64 % | 22.688 mT |
> | 20 mm | 4.36 % | 4.290 mT |
> | 50 mm | 374 % | 0.104 mT |
>
> The 10 mm value is converged and the 50 mm value is not remotely. At n=7 it is 0.49 mT
> against a converged 0.104, and it is still 16 % out at n=13. The paper's 1.0 mT corresponds to
> an array shorter than the CAD's 340 mm. No 50 mm stray figure in this project should be
> cited, including the 0.4 mT in `field_verification.json`, until the array length is set to
> the CAD value and the model converged.
>
> This needs no mesh: magpylib's Cuboid is an exact analytic solution for a uniformly magnetised
> block, so the field is already three-dimensional. What was missing was the convergence check.
RESOLVED 2026-07-23, see CHANGELOG.md P2-03.
Paper quotes 22.7 / 4.7 / 1.0 mT at 10 / 20 / 50 mm. `verify_field.py` reproduces
22.7 mT at 10 mm exactly but gives 4.3 and 0.4 mT at 20 and 50 mm. Likely sensitivity
to modelled array length (edge effects dominate the far field). The 10 mm value is the
one that sets the keep-out spec, so this is minor, but resolve it before anyone cites
the 20/50 mm numbers.

### P4. Brake fin temperature rise conflates per-shot with per-campaign: MEDIUM PRIORITY
> **Status:** `CLOSED` — resolved; see the entry for what closed it

RESOLVED 2026-07-23, see CHANGELOG.md P2-04.
The paper states the 0.86 kg copper fin sees "an adiabatic 37 K transient rise" per
shot, and later refers to "the adiabatic per-shot rises (0.3 K coil, 37 K fin)".

`analysis/sizing.py` gives 1008 J into 0.86 kg of copper = 3.0 K per shot. The 37 K
figure is the *full 12-shot campaign* total if the fin never radiated between shots
(12 x 1008 J / 331 J/K = 36.5 K).

The design is therefore *less* thermally stressed than the paper claims, but the number
as written is wrong and internally inconsistent.

Fix: state 3.0 K per shot, and 37 K as a bounding campaign-adiabatic case that
radiation between shots relieves. Same correction applies to the coil: 0.28 K per shot,
3.3 K campaign.

---

## P: CAD reconciliation and packaging (found in the 2026-07-23 Fusion 360 CAD build)

> These arose when the parametric design was taken into CAD across nine Fusion documents.
> The CAD is authoritative for geometry and fit only; `analysis/*.py` remains
> authoritative for mass and performance until FEA closes the open items. All
> geometry values below are traceable to `cad/parameters.json`. No number in
> `analysis/*.py` or `paper/paper.tex` has been changed on the strength of the CAD.

### P5. CAD sled mass contradicts the parametric assumption: RESOLVED 2026-07-29
> **Status:** `CLOSED` — resolved; see the entry for what closed it

> RESOLVED. `motor_model.M_SLED` and `sizing.M_SLED` now carry the CAD-derived 9.445 kg
> (P15), not the 4.86 kg parametric estimate. A4 ran, the drawn plate passed all three
> structural bands, and the measurement fell in the decision rule's >= 6.80 kg branch, so the
> rule resolved this rather than a judgement call. Caveat carried forward: 9.445 kg is
> the as-drawn, unpocketed geometry and A4 reports a 17x stress margin, so a rib-stiffened
> chassis would recover mass. Designing one is the open successor to this item
> (`docs/ROADMAP.md`), and it is tracked under E2 rather than here.

Original item follows for the audit trail.

> UPDATE 2026-07-28, A4 structural leg has RUN (CalculiX). The as-drawn 6 mm plate
> passes every declared band: 0.0194 mm airgap closure against a 0.025 mm per-plate budget,
> 33.7 MPa against 587 allowable, first mode 3408 Hz against >200. So there is no
> structural argument for the chassis being lighter than drawn, a lighter one has to be
> designed (rib-stiffened), not assumed. Combined with P15's CAD-derived 9.445 kg, the decision
> rule's >=6.80 kg branch stands and the machine as it exists delivers 16.53 m/s.
The first-pass Fusion sled (6 mm Ti-6Al-4V chassis, stiffness-driven by the ±0.05 mm gap
tolerance under 3.7 kN inter-array attraction, 2.69 kN since A12, no structural FEA behind it) implies a
sled mass of ~7.50 kg. `analysis/mass_properties.py` assumes 4.86 kg, which
`motor_model.py` hard-codes as `M_SLED` and which sets the headline exit velocity. Both
are estimates (one CAD-geometric, one parametric-solid) and neither is FEA-verified. Do
not change the scripts until analysis A4 closes the chassis, specified with a
pre-declared decision rule in `validation/A4_sled_structural.md` (CalculiX or
Code_Aster, both free, both read `cad/step/gen3/EMOCD_Sled_Gen3.step`). Source:
`cad/parameters.json` (sled group, `PROVISIONAL_PENDING_FEA`).

### P6. Payload seating / orientation: RESOLVED (by CAD, 2026-07-23)
> **Status:** `CLOSED` — resolved; see the entry for what closed it

Resolved via the rail interface: the 3U payload now models the four CubeSat Design
Specification corner rails (8.5 mm, `cad/parameters.json` `payload_3u`), which fix seating
and orientation against the sled cradle. No further action.

### P7. Brake sits past the release point: geometry / ConOps, CLOSED 2026-08-10
> **Status:** `CLOSED` — resolved; see the entry for what closed it

The eddy brake occupies x = 1530-1740 mm, beyond the 1500 mm satellite release
point, on an 1800 mm longeron. The sled runs on into the brake after the payload departs
consistent with the fire-then-arrest ConOps, but it forces the track and enclosure to
extend past release, which drives the envelope length (see P9). Source:
`cad/parameters.json` (brake, track).

Closed 2026-08-10 by the Gen4 layout, geometrically. `docs/GEN4_STATUS.md` moves release to
s = 1200 mm on a 900 mm acceleration stroke and puts brake-fin entry at s = 1222 mm, so
the release station sits 22 mm before the fin reaches x = 1530 mm. The fin then occupies the
brake interval over 330 mm of sled travel, s = 1222 to 1552 mm. The release-into-brake overlap
is gone, and it is gone without adding track length. Recorded against A16, which computed
the Gen4 finite-stator thrust on this layout, and P32.

The second half of this entry was never P7's to carry. "It forces the track and enclosure to
extend past release, which drives the envelope length" is true and still true, Gen4 keeps the
track at 1800 mm and the brake at 1530-1740 mm. That is the envelope problem, and the envelope
problem is P9, which is a kill-criterion item with an owner decision attached. P7 asked whether
the *overlap* was a defect. It was, Gen4 resolves it, and nothing is gained by keeping a second
entry pointed at P9's problem.

> What this close is worth, stated plainly. Gen4 is a CAD configuration record and has not
> been exported into this repository, `GEN4_STATUS.md` says so in its own first paragraph, and
> the committed STEP, analyses and baseline remain the Gen3 record. So this closes a geometry
> question against a geometry that is not yet committed. It is closed because the layout
> resolves it and the layout is recorded, not because anything was measured. If the Gen4 export
> lands with a different release station, this reopens.

### P8. Exit velocity provisionally 17.88 m/s pending sled structural FEA: RESOLVED 2026-07-29
> **Status:** `CLOSED` — resolved; see the entry for what closed it

> RESOLVED, and not at 17.88 m/s. That figure came from the 7.50 kg CAD estimate. The
> CAD-derived mass is 9.445 kg, so the rated velocity is 16.537 m/s at 10.7 g, now
> propagated into `analysis/`, `paper/paper.tex`, the figures and every front page. The
> machine is no longer acceleration-limited: at 10.7 g against a 25 g cap it is
> thrust-and-mass limited, which changes what recovering velocity means (mass or current,
> not stroke).

Original item follows for the audit trail.

If the CAD sled mass (P5) holds, exit velocity falls from the script's 20.37 m/s to a
provisional ~17.88 m/s (with acceleration ~12.5 g, efficiency ~24 %, recoil
~71.5 N·s, lifetime multiplier x1.68, all CAD-corrected and provisional). These values
are NOT propagated into `analysis/*.py` or `paper/paper.tex`; the scripts stay
authoritative until analysis A4 locks the sled mass (`validation/A4_sled_structural.md`,
which fixes in advance which of the two estimates wins at which mass). Do not hard-swap
20.37 to 17.88 anywhere. Source: 2026-07-23 CAD Master Plan; see README headline note.
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

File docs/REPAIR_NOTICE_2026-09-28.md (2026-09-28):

# September 2026 engineering record correction

VOLLEY grew quickly, and assumptions that had not been fully checked against source evidence or a matched system comparison entered the main engineering record. Over the past three weeks I have reviewed the direction of the next-generation work and repaired claims that had outrun the evidence. The independent motor-charged launcher-cell bank made the problem clear: it left fired cells installed and did not provide the single reusable, sequentially fed launch path I wanted VOLLEY to investigate.
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

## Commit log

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2026-07-31 A6: re-declare the bands at the current operating point, before running
    The 2026-07-27 bands are written at 20.37 m/s, the operating point abandoned
    when the sled was measured. Running against them would have been P19 a second
    time, so they are marked superseded and left visible rather than edited.
    The replacement is narrower and says so. No GMAT, no OEM ephemerides, no CARA,
    no Space-Track for a real covariance -- so this is a 2-D Pc in scipy against
    astro.py's own propagate, with an assumed covariance stated in the output. It
    does NOT close P1 and the sheet says so twice.
    What it can settle is the question P1 actually raised: whether Pc is robust
    where minimum distance is not. That is a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
2026-07-31 Sweep the front doors against the current state
    The README's first screen said FEA was still outstanding, which stopped being
    true when A4 and A1 ran. SUMMARY said four of nine validations. Both are the
    first thing a visitor reads and both were claims about where the project
    stands, so both were wrong in the way that matters most.
    SUMMARY now carries the mixed result rather than the tally: A5 failed, A12
    found a published number 37 % high and its own explanation backwards, A6
    returned three void rows, and A7 and A9 are outstanding -- A9 being the only
    analysis anywhere here that compares the model against something that actually
    happened.
    The profile README leads with the net 2.58 kJ rathe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
2026-07-31 P30: an acceptance band was set at the easier of two comparators
    Three documents carried an unresolved flag that A7's tip-off band declares
    5 deg/s citing NRCSD-E while a sibling NRCSD ICD says 2, and that this had to
    be settled before the band meant anything. PII-1 was gated on it.
    There is no conflict. They are two different deployers and both numbers are
    right: NRCSD is the internal ISS-airlock one at <2 deg/s/axis, flown hundreds
    of times, and NRCSD-E is the external Cygnus-mounted one at <5, a figure its
    own publisher describes as pending further testing.
    What that leaves is worse than the flag it replaces. The band was set at the
    looser comparator, from the provisional document, with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
2026-07-31 A13: declare the indexing-disturbance bands before the script exists
    astro.py's entire host-interaction budget is one line, 4.0*DV, the payload's
    momentum. Between shots a cassette follower moves a satellite across the
    structure and the sled returns 9.445 kg down 1.5 m of track, and neither is in
    any budget here. Same class as the bank ESR: a budget published as complete
    that omits a term the hardware will have.
    The bands are written to be capable of failing, because E24 explicitly forbids
    concluding this is negligible until it is computed -- P16 was "probably fine"
    too. The deliverable is a number with a band it could have missed, not a
    paragraph that begins from smallness.
    Host inertia i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
2026-07-31 A13 fails, and E24 was worried about the wrong mass
    astro.py's whole host-interaction budget was 4.0*DV, the payload's momentum.
    A13 adds the two masses that move between shots, and four of seven bands pass.
    The indexing is negligible, exactly as E24 guessed: 0.208 N.s, 0.31 % of the
    shot impulse, 0.007 deg/s at a 500 kg host.
    The sled return is not, and it appears nowhere in E24 or anywhere else here.
    9.445 kg travelling 1.5 m back to the breech is 4.723 N.s -- 7.14 % of the
    shot, 23x the indexing term, and the largest unbudgeted term in the host
    interaction by a wide margin. At a 500 kg host that leaves 0.161 deg/s against
    a 0.05 band, and nulling it takes 8.2 s against a 2 s band and a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
2026-07-31 Shortlist A9's candidate objects so it can be run elsewhere
    A9 is the only analysis specified anywhere in this project that would compare
    the model against something that actually happened. Nine validations have now
    run and not one of them has touched a measurement.
    Re-tested the block: celestrak.org 403s at the CONNECT, logged by the proxy as
    a policy denial, and Space-Track needs an account regardless. It genuinely
    cannot run here.
    What was missing besides the data was the object selection, and that can be
    built from published mission records without the element feed. QB50 is the
    right cohort -- no propulsion by design, and eight of them went up on PSLV-C38
    into the ~505 km SSO that A9 s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
2026-08-03 The winding-thickness quadrature was high, and the rated point moves to 16.388 m/s
    The winding-thickness average in both motor_model.py and A1 used endpoint-inclusive samples with an unweighted thickness/sample-count sum. They therefore agreed with each other while sharing the same quadrature defect.
    I replaced that average with nine-point Gauss-Legendre quadrature before rerunning either side. The rated model now gives Kt = 11.0258 N per kA/m (11.03 displayed), +/-0.99% ripple, 1389.255 N thrust, 16.388 m/s at 10.533 g in 158.6 ms, and 338.8 A peak current. The bank supplies 2850.9 J; 291.4 J returns during regenerative braking; the eddy brake absorbs 934.7 J; and net electrical-to-payload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
    [motor_results.json]
2026-08-03 A6's bound and A13's residual rate were wrong; A12 survives a larger surface
    A13 treated the peak angular momentum of an internal mass as residual host rate after that mass stopped. An ideal rigid body returns to zero rate; it retains a transient counter-rotation and an attitude offset. Rows 3 and 4 remain FAIL at 0.136 deg/s for the 500 kg host and 0.443 deg/s for the 200 kg host, row 7 is VOID, and the old 8.2 s rate-null time, 18.1 s cadence floor, 6.9 s optimum and counter-mass conclusion are superseded. Structural ringing is not in this model, so E25 remains open. A6's 3.7e-8 result swept one fixed 5:1:1 covariance shape and was not a bound over every covariance. At the old 14.49 km ge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
2026-08-03 The brake fin was counted twice, and its thermal model used the wrong length
    The 0.344 kg aluminium brake fin already exists in the Gen3 STEP assembly and was also included inside the 1.20 kg eddy-brake lump. Removing that duplicate closes the system at 76.5 kg dry and 124.5 kg loaded. The thermal calculation used a 300 x 80 x 4 mm fin even though the CAD fin is 120 x 80 x 4 mm. At the corrected mass it rises about 7 K per shot and 85 K over twelve shots without cooling. That is an adiabatic bound rather than a temperature prediction, and E26 now records the missing transient thermal model. Twelve shots at 65.552 N s are 786.624 N s, not 0.98 kN s. The corrected bank minimum is 0.947 F aga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
2026-08-03 Gen4 reaches the finite stator edge, so Phase I remains the rated baseline
    Record the open Fusion assembly, its 900 mm stationing, the 22 mm release-to-brake gap, and the named export gate without assigning Phase I performance to the new geometry.
    Open P32 and E27 for the missing position-dependent force calculation, propagate the state through the changelog, roadmap, CAD record, validation boundary, front-door documents, and ADR index, and retain every existing failed or unresolved result.
2026-08-05 The coilgun was dropped over acceleration and EMI, and only one of those was ever calculated
    The reason on record for the mid-2025 architecture change was velocity accuracy. That is
    true but it is not what stopped me, and my 2021-2025 notebooks say so: the acceleration was
    enormous and the EMI environment was awful, and both defeat the point of supporting an
    unmodified CubeSat.
    I have added that chain to docs/HISTORY.md in the notebook's own words, with the seven
    constraints the linear synchronous motor answered at once, and separated the half of the
    argument that is now a number from the half that never was. ADR-003 carries the acceleration
    comparison against Feng et al. The EMI judgement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
2026-08-05 The paper credited a winding inductance that did not exist anywhere in the model
    paper.tex said the 20-40 kHz switching is "high enough that the current ripple is filtered
    by the winding inductance". There was no henry in analysis/, and no phase current either:
    motor_model.shot() integrates in sheet current and the I_peak it reports is the DC-link
    current drawn from the bank, not the current in a conductor.
    The model could not have produced that inductance. A sheet-current model is turns-invariant,
    so L scales as N^2, phase current as 1/N, and the stored field energy is the same either way.
    The bus is what fixes the turns count: the inverter has to synthesise the phase voltage the
    machine d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
2026-08-05 The companion generator was emitting a pre-quadrature operating point
    Regenerating the companions surfaced it: tools/export_companion.py writes the "what
    reproduces" table into both generated READMEs, and it still claimed Kt = 11.22 N per kA/m
    agreeing to 0.07 %, and 16.537 m/s at 10.7 g. All three predate the quadrature correction,
    and both companions have been publishing them since 2026-08-03.
    Corrected to 11.03, 0.03 %, and 16.388 m/s at 10.53 g.
    Also swept the live current-state claims my previous pass missed, keeping the superseded
    run-sheet and ADR records intact because those are dated evidence rather than assertions:
    docs/RESULTS.md said the current point was 16.54 m/s inside a his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
2026-08-05 A14: declare the EMI bands, before the script that will test them exists
    E12 has been open since the first defect sweep and is the oldest unquantified item here. The
    2025 decision to drop the coilgun rested partly on the electromagnetic environment and never
    computed it; my other launch paper lists the same analysis in its abstract and never performs
    it; and the question has now been asked from outside the project. P33 supplied the phase
    current and winding inductance that make it computable, so there is no longer a reason to
    carry it.
    Eight bands, declared before validation/emi/emi_scoping.py exists. The standoffs are read from
    cad/parameters.json rather than assumed: the array back face i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
2026-08-05 A14 ran: the dominant electromagnetic term is the magnets, not the drive
    Six of eight declared bands pass, band 4 fails at 611x, band 5 is void as declared. Bands were
    committed at c274473 before validation/emi/emi_scoping.py existed and none was widened.
    The payload's nearest face sits 6 mm behind the Halbach array back face, read from
    cad/parameters.json rather than assumed, and the static field there is 61.1 mT: 1357x Earth's
    field and 611x the full scale of the magnetometer class a CubeSat carries. The entire switching
    transient produces 11.8 mV from commutation and 36.0 mV from 20 kHz ripple in the same
    unshielded loop. A customer worried about the inverter is worried about the wrong t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
2026-08-05 A15: declare the POEM campaign bands, and settle the cadence P31 has carried since the start
    ADR-020 adopts 1200 s as the ConOps inter-shot interval. It is the number astro.py's
    conjunction model, the realignment period and the deployment safety case were already computed
    against, so adopting it invalidates nothing, while 10-20 s would need A6 re-run against a
    geometry this project has never evaluated. The 10-20 s figure was never derived: the paper
    attributed it to supercapacitor recharge, recharge is 8.6 to 17.2 s, so the range looked right
    and went unexamined, which is why the error survived.
    A13's failed bands are NOT re-declared against the new interval. P31 explicitly warned that
    doin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
2026-08-05 A15: generate the POEM campaign, and the cross-check catches three of my own band errors
    build_poem_campaign.py writes one GMAT script per reference orbit, placing twelve satellites on
    their post-burn orbits with mean anomaly rewound by n*t_k, the staggering emocd_fleet already
    uses. Delta-v is read from motor_results.json and the orbit definition is imported from
    astro.py, so neither can drift. Predictions at 450 km/51.6: 0.1229 deg max inclination change,
    117.2 km altitude extent, 13.18 deg of RAAN separation after 90 days, and semi-major axis
    agreeing with astro.boosted_elements to 0.0000 percent.
    The cross-check earned its place immediately. It first reported zero inclination spread and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
2026-08-05 A7-R: the release has 50.7 microseconds of unbalanced push before tip-off fails
    A7 remains unrun and is still marked so. Project Chrono is unavailable here, but the reason
    that matters less than the second one: the release mechanism A7 would simulate is not defined
    anywhere in this repository. The paper says force is removed in the coast-trim zone and the
    sled then enters the brake while the satellite departs, and says nothing about how the cradle
    rails disengage, in what order, with what friction, or over what time. A multibody model of an
    undefined mechanism gives a number with no provenance.
    So A7-R computes what is answerable from the geometry that is fixed: how symmetric the release
    ha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
2026-08-06 Declare bands for A16 and A17 before either script exists
    A16 closes E27: thrust against sled station when the Gen4 array leaves the finite stator. The
    340 mm array is fully over the stator only while s <= 1051.5 mm, so the final 148.5 mm of the
    900 mm stroke runs at partial overlap and 191.5 mm of 340 remains at release. Band 1 is the
    self-consistency test that matters: over the fully-overlapped interval this must reproduce the
    periodic model within 2 %, because that is the one regime where the two describe the same
    physics and a disagreement there is a bug rather than a finding.
    Band 4 is deliberately not pass/fail. The method truncates an otherwise-periodic winding at the
    stator end, so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
2026-08-06 A16 and A17: Gen4 loses 18 % of exit velocity, and the track ripple resonance is real
    Both ran against bands committed at 13b4b3b before either script existed. Neither band was
    widened.
    A16 closes E27. Thrust per metre of overlapped array is 4086.0 N/m, and at full overlap that
    reproduces motor_results' F_cmd to 0.000 percent -- the self-consistency test the whole
    analysis turns on, because the fully-overlapped interval is the one regime where this and the
    periodic model describe the same physics. Force at release falls to 782.5 N, 56.3 percent of
    full, matching the overlap fraction exactly, which is why band 2 was declared report rather
    than pass/fail.
    The finding is the velocity. Work ov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
2026-08-10 Gen5: CAD generated from parameters, and checked against them
    build_gen5.py reads cad/parameters.json and emits STEP and STL for all eight documents.
    Nothing is drawn, so it cannot drift from the parameters, and it regenerates
    byte-identically from a clean clone -- the STEP header timestamp is normalised precisely
    so a changed clock cannot be mistaken for changed geometry.
    --check reads 23 dimensions back out of the built solids and compares them to the
    parameter file. It caught three errors on its first run: a longeron built to the
    roller-channel width instead of the track's overall width, a gate pin extruded outboard
    because a CadQuery XZ workplane extrudes along -Y, and a check that call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
    [VOLLEY_Brake_Gen5.step, VOLLEY_Brake_Gen5.stl, VOLLEY_Enclosure_Gen5.step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]
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2026-08-13 A28: the velocity loop, designed against margins rather than asserted
    Four of six bands fail. The controller is feedback-linearised, so the loop
    transfer is Kp/s exp(-s tau) and Kp is the gain crossover in rad/s, not a
    current gain. At 3500 s^-1 that is 557 Hz -- above both track modes -- with
    -50.4 deg phase margin and -3.86 dB gain margin at 0.7 ms of total lag.
    Two things concealed it: closed_loop_mc feeds back the undelayed state, and
    the command clip turns an unstable loop into a bang-bang relay whose mean
    follows the feedforward term.
    KP_VELOCITY = 195 s^-1, the designed maximum holding 50 deg of phase margin
    at 0.6 ms and bandwidth at or below a third of the 109 Hz first mode. Gain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
    [motor_results.json]
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2026-08-14 Apply the depth-resolved Kt and the three decisions beside it
    Kt 11.0258 to 10.5386 by making the thrust integral depth-resolved rather
    than pasting a factor; nz=1 still reproduces the superseded value, so A2's
    0.9558 ratio stays checkable. v_exit 16.388 to 16.029.
    That dropped the open-loop ceiling below the 16.2 fleet setpoint, which is
    the condition ADR-014 forbids, so V_FLEET moves to 15.8 -- holding the
    fraction rather than the number.
    Regen section 240 to 39 mm so both it and the eddy fin fit the arrest
    section. Dropping regen was recommended first and withdrawn: it worsens E34.
    Packaging enters the rollup as a labelled 8 kg placeholder. Gen4 retired.
    Every headline number moved the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
    [motor_results.json]
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2026-08-16 A43: the bottle does not warm back up, and P64 resolves the other way
    P64 was the only open number in the Gen6 architecture, worth about 1.3 kg of
    store. A42 modelled the reservoir as adiabatic, which is right for a
    follows it, and both A42 and ADR-032 recorded that the truth would sit nearer
    the isothermal figure.
    It does not. Conduction through stagnant nitrogen gives a 17460 s time constant
    against a 1200 s cadence, fourteen and a half times the wait between shots. The
    two paths that would carry heat into the gas are both absent here: nitrogen is
    a homonuclear diatomic and does not absorb infrared, so the wall c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
    [VOLLEY_Reservoir_Gen6.step, VOLLEY_Reservoir_Gen6.stl, reservoir_thermal.json]
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2026-08-16 A second CAD implementation, and it found the sled rollers outside their channels
    cad/scad/gen5.scad builds the same eight documents as build_gen5.py, in OpenSCAD's
    CSG kernel rather than CadQuery's B-rep, and exports STL rather than STEP. Neither
    reads the other. Both read parameters.scad, generated from parameters.json by
    cad/tools/make_scad_params.py, because OpenSCAD has no JSON parser and a model
    that pasted its dimensions would be a second place for them to be wrong.
    Everywhere else this project checks a result by computing it a second way. The
    geometry never had that treatment: parameters.json had been checked against
    exactly one model built from it, and every guard in tools/ compare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
    [VOLLEY_Brake_Gen5.step, VOLLEY_Payload_3U_Gen5.step, VOLLEY_Sled_Gen5.step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]
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2026-08-16 Say on the front page which generation a reader is looking at
    The pictures on the front page are Gen4, the numbers are Gen5, and the design
    target is Gen6. Nothing said so, and a reader had no way to infer it.
    docs/GENERATIONS.md sets the three side by side with what each was for, what it
    fixed and what it cost, and renders all three: Gen4 from Fusion, Gen5 and Gen6
    in Cycles from their committed STL sets. The caption states plainly that the
    three images are not directly comparable -- where they differ in shape that is
    the design, where they differ in finish that is the tool.
    The comparison does not flatter the current target. Gen6 is better on velocity
    and on added mass per satellite, and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
    [VOLLEY_Magazine_Cassette_Gen6.stl, VOLLEY_Stage_Rail_Gen6.stl]
2026-08-16 "Generated" now reads as something this project is not, so the CAD is script-built
    The word describes a CadQuery script reading a JSON parameter file --
    deterministic, byte-reproducible, and nothing else. It no longer reads that way
    on its own, and the ambiguity sits on the most public surface this work has.
    Renamed throughout live prose: script-generated becomes script-built, "generated
    from parameters.json" becomes "built from parameters.json", "a generated model"
    becomes "a script-built model". ADR-026 is renamed from 026-generated-cad.md to
    026-cad-built-from-parameters.md, retitled, and carries a note recording the
    rename and that the decision itself is unchanged. Every reference to it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
    [gen5.scad]
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2026-08-16 ADR-033: Gen6 gains a motor that steers rather than throws
    Gas supplies the energy, a 39.7 mm stator at the muzzle supplies the control.
    It is energised only after the gas has finished and corrects the velocity the
    gas actually produced. It never throws the payload.
    The reason is A44. Gen6 as adopted cannot command velocity, only set it, before
    a 133 ms open-loop expansion whose spread is 93.4 per cent a seal friction
    nobody has measured -- and a fivefold better transducer moves that by 0.008 per
    cent. There is no instrumentation route to the product's central claim. A48
    prices the alternative at 2.021 per cent of the shot, 1.822 per cent of the
    stroke and 0.340 kg, and its band 6 says the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
    [VOLLEY_Carriage_Gen6.step, VOLLEY_Chamber_Gen6.step, VOLLEY_Magazine_Cassette_Gen6.step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]
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2026-08-19 A55: the trim section was 3.57x under-authority, and resizes to 144 mm
    Four of nine. Band 1 reproduced A44 to four decimal places -- 1.1133 %
    against its stored 1.11334669, and the seal's variance share at 93.4 %
    against A44's 93.4 -- which is what band 1 exists to establish.
    It caught a bug in this run's own script before it caught anything
    about the design. The first run returned 1.2353 % and failed band 1 by
    11 %, because trim_authority.py referenced the transducer's full scale
    to the 200 bar store where gen6_dispersion.py uses a fixed 50 bar. The
    band was not widened. The script was fixed and the run repeated. Fourth
    time in this project that a band declared beforehand has found a defec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
    [VOLLEY_Trim_Stator_Gen6.step, VOLLEY_Trim_Stator_Gen6.stl]
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2026-08-19 P84 again: fill_window.py was the second instance and the first fix missed it
    The repair committed with A55 covered precharged.py and stopped there.
    fill_window.py went on declaring P_CHARGE = 50e5, and it feeds A42, A43
    and A45 -- so the same defect was live in a second file while the entry
    was marked corrected.
    fill_window now derives the charge pressure and chamber volume from
    cad/parameters.json, with A42's own point frozen as P_CHARGE_A42 and
    V_CHAMBER_A42 so its run sheet stays reproducible.
    The entry is annotated rather than reopened, because the annotation is
    the useful part: the hole P84 described was never that one constant was
    stale, it was that nothing compares the parameter fi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
    [reservoir_thermal.json]
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2026-08-20 A56: the reservoir sized at ADR-034's charge pressure, and it is smaller than claimed
    Eight of nine. Band 1 reproduced A43's 9.550 L and its 17460 s
    conduction time constant exactly, so the two are the same model at two
    pressures.
    Sized at 22.7258 bar the reservoir is 3.460 L and the store 3.1216 kg,
    against A43's 9.550 L and 5.3804 at 50 bar. The bottle falls 63.8 %
    where the gas falls 54.55 %, because a lower target pressure lets it be
    drawn further down before it can no longer fill the chamber. That
    nonlinearity had not been claimed, and it is why the prediction of
    about 4.3 L came in at 3.46.
    So ADR-034's store figure was pessimistic rather than optimistic. Its
    falsifier 2 asked whethe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
    [VOLLEY_Reservoir_Gen6.step, VOLLEY_Reservoir_Gen6.stl, reservoir_resized.json]
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2026-09-28 Correct engineering record and withdraw unselected launcher bank
    [VOLLEY_Carriage_HistoricalStudy.step, VOLLEY_Carriage_HistoricalStudy.stl, VOLLEY_Chamber_HistoricalStudy.step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]
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2026-10-09 Publish Gen5 computational review evidence and corrected mission claims
    [VOLLEY_Carriage_LegacyStudy.step, VOLLEY_Carriage_LegacyStudy.stl, VOLLEY_Chamber_LegacyStudy.step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]
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

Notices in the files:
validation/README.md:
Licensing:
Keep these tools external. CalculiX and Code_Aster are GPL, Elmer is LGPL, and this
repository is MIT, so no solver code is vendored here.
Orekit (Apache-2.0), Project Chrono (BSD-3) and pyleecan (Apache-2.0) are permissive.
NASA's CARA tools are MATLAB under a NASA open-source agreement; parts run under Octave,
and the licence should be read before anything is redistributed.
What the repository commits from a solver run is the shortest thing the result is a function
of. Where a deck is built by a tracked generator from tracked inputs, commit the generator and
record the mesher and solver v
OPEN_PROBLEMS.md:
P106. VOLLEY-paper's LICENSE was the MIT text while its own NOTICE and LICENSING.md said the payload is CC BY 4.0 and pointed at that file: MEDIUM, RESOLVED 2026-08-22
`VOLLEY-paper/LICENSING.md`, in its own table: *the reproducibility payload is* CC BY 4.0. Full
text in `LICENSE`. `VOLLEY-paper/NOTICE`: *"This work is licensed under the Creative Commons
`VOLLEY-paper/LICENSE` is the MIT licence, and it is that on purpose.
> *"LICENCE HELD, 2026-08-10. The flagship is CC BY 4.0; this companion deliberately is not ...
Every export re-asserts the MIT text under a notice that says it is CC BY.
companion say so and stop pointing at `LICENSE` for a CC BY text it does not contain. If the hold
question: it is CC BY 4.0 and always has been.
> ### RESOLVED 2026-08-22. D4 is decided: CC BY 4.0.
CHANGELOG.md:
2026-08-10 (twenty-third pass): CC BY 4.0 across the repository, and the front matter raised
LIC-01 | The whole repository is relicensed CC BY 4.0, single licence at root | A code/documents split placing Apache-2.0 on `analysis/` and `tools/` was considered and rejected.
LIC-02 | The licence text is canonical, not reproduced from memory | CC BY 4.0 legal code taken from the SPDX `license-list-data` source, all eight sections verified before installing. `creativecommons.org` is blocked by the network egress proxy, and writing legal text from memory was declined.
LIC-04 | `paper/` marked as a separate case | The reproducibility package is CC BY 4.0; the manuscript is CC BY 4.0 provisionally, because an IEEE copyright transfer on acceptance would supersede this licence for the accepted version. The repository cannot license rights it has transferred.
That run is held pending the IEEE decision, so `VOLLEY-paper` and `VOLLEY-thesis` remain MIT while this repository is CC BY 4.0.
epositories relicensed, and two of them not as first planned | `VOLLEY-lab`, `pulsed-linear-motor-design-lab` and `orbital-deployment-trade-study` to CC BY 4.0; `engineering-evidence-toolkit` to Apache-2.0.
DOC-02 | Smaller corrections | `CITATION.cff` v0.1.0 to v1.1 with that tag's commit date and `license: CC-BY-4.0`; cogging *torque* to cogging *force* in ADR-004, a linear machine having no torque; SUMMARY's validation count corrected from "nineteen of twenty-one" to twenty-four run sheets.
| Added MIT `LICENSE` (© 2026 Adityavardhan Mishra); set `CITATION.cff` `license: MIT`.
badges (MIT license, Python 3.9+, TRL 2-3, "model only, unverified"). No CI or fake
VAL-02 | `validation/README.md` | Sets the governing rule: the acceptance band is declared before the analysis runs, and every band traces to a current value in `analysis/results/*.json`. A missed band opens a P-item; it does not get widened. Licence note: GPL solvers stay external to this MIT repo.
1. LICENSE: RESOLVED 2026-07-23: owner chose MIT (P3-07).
